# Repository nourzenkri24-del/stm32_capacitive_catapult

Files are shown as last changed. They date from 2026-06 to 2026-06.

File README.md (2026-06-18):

# stm32_capacitive_catapult

A catapult whose firing angle and power are controlled remotely by hand proximity, without any physical contact. The system uses a capacitive copper plate electrode to detect hand distance and translates it into real-time servo motor commands via an STM32 microcontroller.

> **Academic project** — Prototyping module, Mines Saint-Étienne (ISMIN), 2025–2026  

---

## How it works

A copper plate electrode forms a capacitor with the user's hand. As the hand moves closer, the total capacitance increases, which causes the frequency of a signal conditioner circuit to decrease (following F = 1 / (2 × R6 × Ctot)). The STM32 measures this frequency using a timer in **input capture mode**, applies a **10-point moving average filter** to smooth noise, then maps the filtered frequency to a servo angle via a linear law. Three servo motors control the catapult's firing angle, trajectory shape, and spoon locking mechanism.

```
Hand proximity → Capacitance variation → Signal conditioner (freq output) → STM32 input capture (TIM2)
→ Moving average filter → Frequency-to-angle mapping → PWM output (TIM1) → 3x Servo motors
```

---

## My contribution

- Full STM32 firmware (STM32CubeIDE, HAL): frequency measurement, filtering, state machine, PWM generation
- Timer configuration: TIM2 in input capture for frequency measurement, TIM1 for 3-channel PWM servo control
- 10-point moving average filter to stabilize noisy capacitive readings
- 6-state finite state machine controlling the full firing sequence
- KiCad system-level schematic (MCU + conditioner + servos + button)
- 3D mechanical design of the catapult structure
- Experimental calibration of sensor frequency range (29–62 kHz) and servo PWM limits (CCR 150–900)

> Signal conditioner circuit (schematic + PCB) provided by the school (Mines Saint-Étienne). I studied its operating principle and implemented the full STM32 integration and system logic.

---

## Hardware

| Component | Role |
|---|---|
| STM32 Nucleo L432KC | Microcontroller (32 MHz) |
| Copper plate electrode | Capacitive proximity sensor |
| Signal conditioner | Converts capacitance to variable-frequency square wave |
| Servo 1 (HS422) | Controls firing angle (trajectory shape) - range: 40°–125° |
| Servo 2 (HS422) | Controls horizontal orientation - range: 0°–180° |
| Servo 3 (HS422) | Locks / releases the spoon mechanism |
| Push button | Triggers state transitions |

**Sensor frequency range:** 29 kHz (hand close) → 62 kHz (hand far)  
**PWM period:** 20 ms (50 Hz) | CCR range: 150 (0°) → 900 (180°)

---

## State Machine

All transitions are triggered exclusively by button press, ensuring no accidental firing.

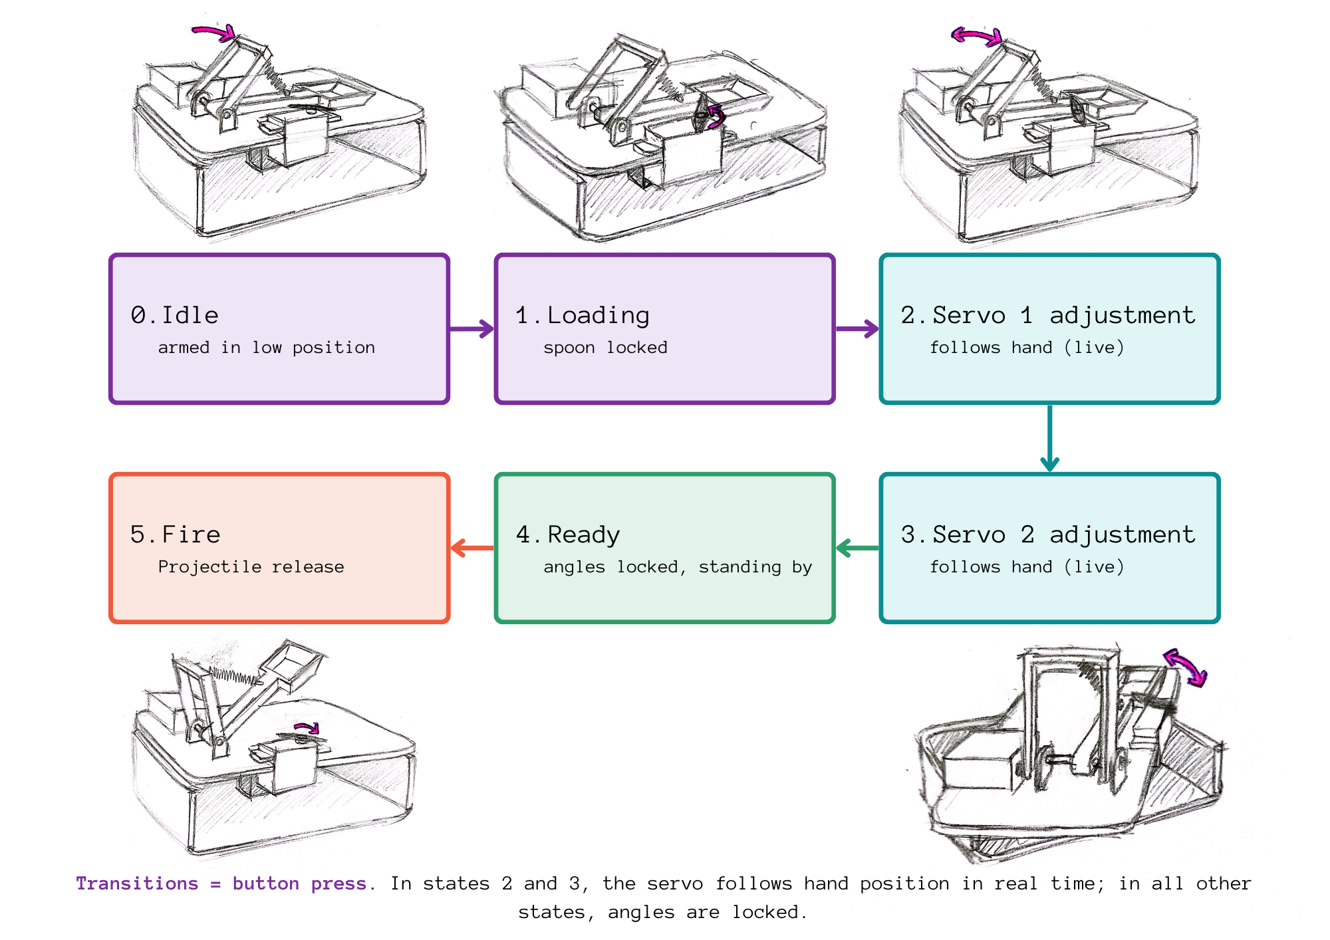
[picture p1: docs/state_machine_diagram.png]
State machine diagram


| State | Name | Description |
|---|---|---|
| 0 | Idle | Armed in high position, spoon released |
| 1 | Loading | Spoon locked by servo 3 |
| 2 | Servo 1 adjustment | Firing angle follows hand in real time |
| 3 | Servo 2 adjustment | Horizontal orientation follows hand in real time |
| 4 | Ready | All angles locked, waiting for fire command |
| 5 | Fire | Servo 3 releases spoon → projectile launched |

> In states 2 and 3, servo angles track hand position continuously. In all other states, angles are locked to their last set value.

---

## Firmware Architecture

```
main.c
├── HAL_TIM_IC_CaptureCallback()   ← ISR: measures period between rising edges (TIM2 CH1)
├── moving_average1()              ← 10-point sliding window filter
├── freq_to_angle()                ← Linear mapping [FREQ_MIN, FREQ_MAX] → [0°, 180°]
├── servo_angle_to_ccr()           ← Angle → PWM compare register value
└── main loop
    ├── Button polling + debounce (200 ms)
    ├── State machine transitions
    └── Per-servo angle selection based on current state → PWM update
```

Key implementation details:
- `diff1` (ISR-shared variable) is read with IRQ disabled to ensure atomic access
- Frequency is clamped to [FREQ_MIN, FREQ_MAX] before angle conversion to prevent out-of-range servo commands
- Servo 1 mechanical limits (40°–125°) enforced separately from servo 2 (0°–180°)

---

## System Schematic

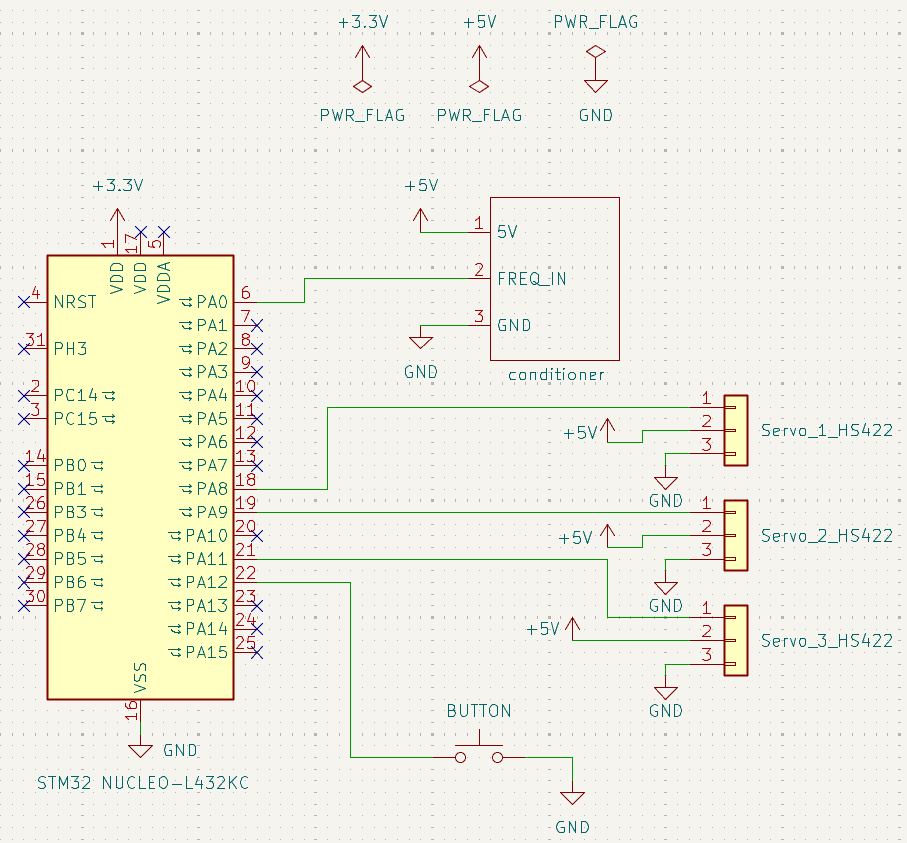
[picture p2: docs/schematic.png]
System schematic


---

## Demo

| | |
|---|---|
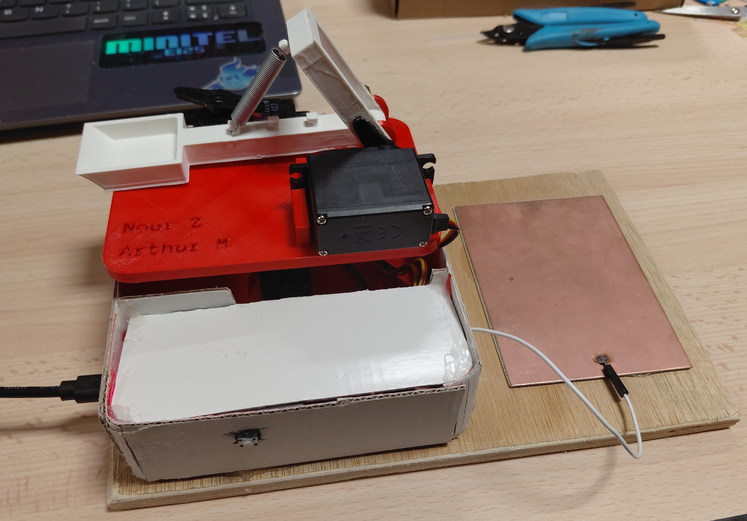
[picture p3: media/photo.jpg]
Catapult photo
|  | See [`media/`](media/) for demo video |

---

## Repository Structure

```
stm32-catapult/
├── Core/                        # STM32 firmware source (CubeIDE/HAL)
├── Drivers/                     # HAL + CMSIS libraries
├── schematics/                  # KiCad system schematic + PNG export
├── docs/
│   ├── state_machine_diagram.png
│   ├── schematic.png            # Schematic png
├── media/                       # Photos and demo video
├── cad/                         # 3D mechanical design files
├── stm32_catapult.ioc           # CubeMX configuration
├── STM32L432KCUX_FLASH.ld       # Linker script
└── README.md
```

---

## Known Limitations

- The frequency-to-distance relationship is hyperbolic (F ∝ 1/d), resulting in non-uniform angular resolution across the detection range
- The conditioner is sensitive to electromagnetic interference, introducing frequency fluctuations
- The capacitance formed between the electrode and the hand depends on hand surface, posture, and individual morphology — the system is not self-calibrating per user

## Possible Improvements

- Software compensation for the non-linearity of the transduction law
- Startup calibration procedure to normalize the frequency-angle mapping per user
- Guard electrode around the sensor plate to reduce EMI sensitivity

---

## Built With

- STM32CubeIDE (HAL, CubeMX)
- KiCad 10
- PartQuest Explore (circuit simulation)
- Fusion 360 / [your 3D tool] (mechanical design)

---

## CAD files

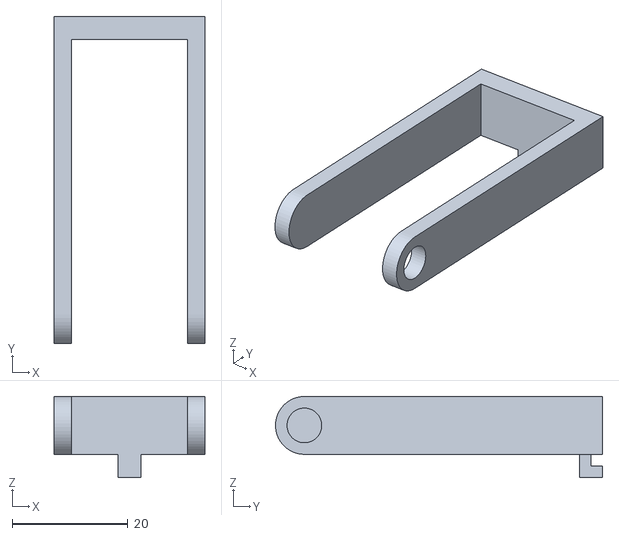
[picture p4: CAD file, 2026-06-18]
cad/spring_support.stl
26.0 x 56.5 x 14.0

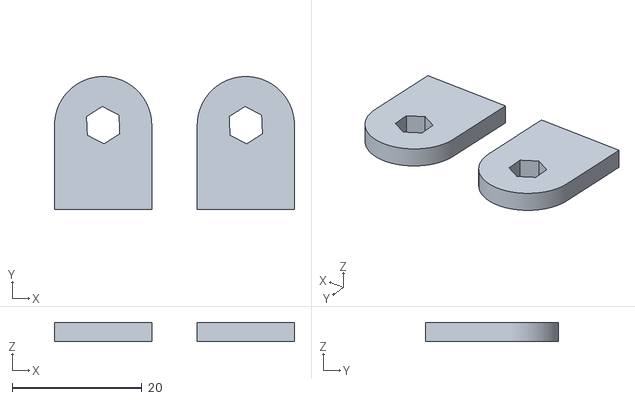
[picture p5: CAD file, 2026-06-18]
cad/part_embedded_in_the_base.stl
37.0 x 20.5 x 3.00

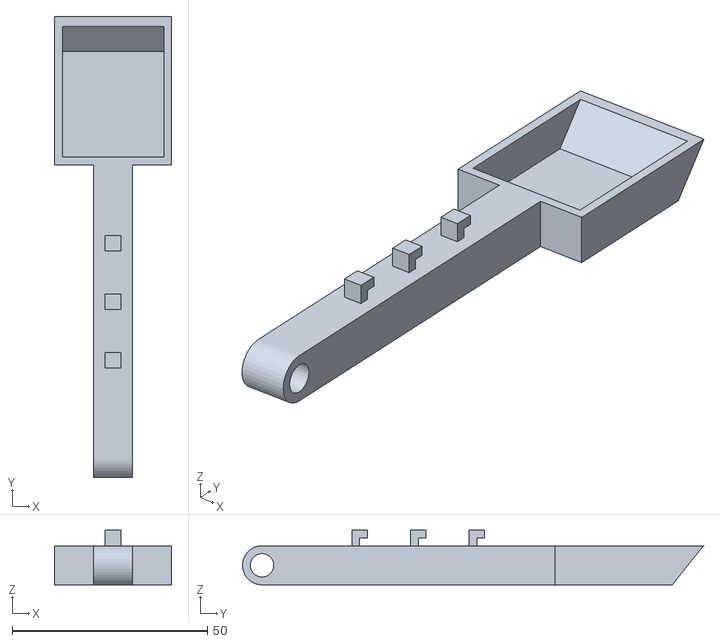
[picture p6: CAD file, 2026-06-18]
cad/Spoon.stl
30.0 x 118.0 x 14.0

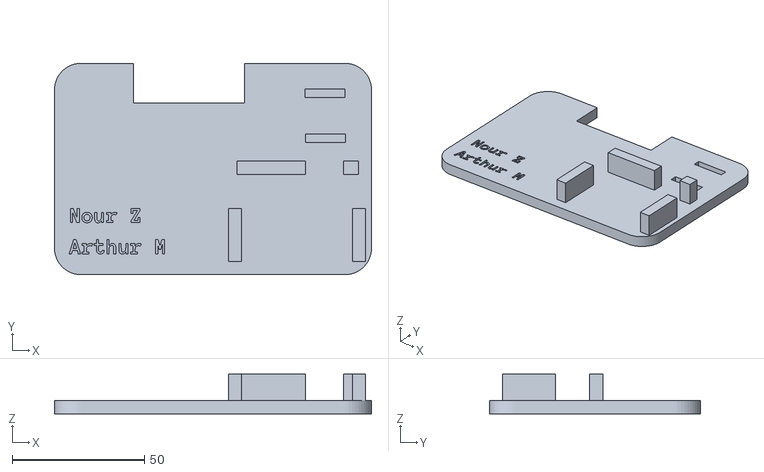
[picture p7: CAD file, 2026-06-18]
cad/base.stl
120.0 x 80.0 x 15.0

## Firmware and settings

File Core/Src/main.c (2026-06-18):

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
/* Includes ------------------------------------------------------------------*/
#include "main.h"

/* USER CODE BEGIN Includes */
#include <stdio.h>
#include <string.h>
/* USER CODE END Includes */

/* USER CODE BEGIN PTD */

// States of the state machine of the catapult
typedef enum {
    ETAT_REPOS      = 0,  // Initial position / Idle
    ETAT_RECHARGE   = 1,  // Recharge
    ETAT_SET_SERVO1 = 2,  // Interactive adjustment of servo 1
    ETAT_SET_SERVO2 = 3,  // Interactive adjustment of servo 2
	ETAT_ATTENTE    = 4,  // Wait
    ETAT_CATAPULTE  = 5,  // Fire
} Etat_t;

/* USER CODE END PTD */

/* USER CODE BEGIN PD */
#define TIMER_CLOCK_HZ   32000000.0f  // TIM2 clock frequency (Hz)
#define FREQ_MIN         29000.0f     // Minimal frequency of the entry (Hz)
#define FREQ_MAX         62000.0f     // Maximal frequency of the entry (Hz)
#define FILTER_SIZE      10           // Filter size
#define DEBOUNCE_MS      200          // Anti-rebound button (ms)

// Mechanical limits servo 1
#define SERVO1_ANGLE_MIN 40
#define SERVO1_ANGLE_MAX 125

// Mechanical limits servo 2 and 3
#define SERVO2_ANGLE_MIN 0
#define SERVO2_ANGLE_MAX 180
/* USER CODE END PD */

TIM_HandleTypeDef htim1;
TIM_HandleTypeDef htim2;

UART_HandleTypeDef huart2;

/* USER CODE BEGIN PV */

// ISR variables (volatile)
static volatile uint32_t ic1_prev       = 0;
static volatile uint32_t diff1          = 0;
static volatile uint8_t  first_capture1 = 0;
static volatile uint8_t  ready1         = 0;

// Filter
static uint32_t capture_buffer1[FILTER_SIZE] = {0};
static uint8_t  filter_index1  = 0;
static uint32_t filter_sum1    = 0;
static uint8_t  filter_count1  = 0;  // Number of valid samples (≤ FILTER_SIZE)

// State machine
static Etat_t   etat           = ETAT_REPOS;
static uint8_t  angle1_bloque  = 90;
static uint8_t  angle2_bloque  = 90;
static uint32_t last_button_time = 0;

// Mesured frequency
static uint32_t freq1 = 0;

// UART for debug
static char     uart_buf[64];
static uint16_t print_cnt = 0;

/* USER CODE END PV */

void SystemClock_Config(void);
static void MX_GPIO_Init(void);
static void MX_USART2_UART_Init(void);
static void MX_TIM2_Init(void);
static void MX_TIM1_Init(void);
/* USER CODE BEGIN PFP */
static uint32_t servo_angle_to_ccr(uint8_t angle, uint8_t angle_min, uint8_t angle_max);
static uint32_t moving_average1(uint32_t new_val);
static uint8_t  freq_to_angle(uint32_t freq);
/* USER CODE END PFP */

/* USER CODE BEGIN 0 */

// convert angle to ccr
static uint32_t servo_angle_to_ccr(uint8_t angle, uint8_t angle_min, uint8_t angle_max)
{
    if (angle < angle_min) angle = angle_min;
    if (angle > angle_max) angle = angle_max;
    return 150 + ((uint32_t)angle * 750) / 180;
}

// Moving average filter
// new_val is the new value to integrate.
static uint32_t moving_average1(uint32_t new_val)
{
    filter_sum1 -= capture_buffer1[filter_index1];
    capture_buffer1[filter_index1] = new_val;
    filter_sum1 += new_val;

    filter_index1 = (filter_index1 + 1) % FILTER_SIZE;

    if (filter_count1 < FILTER_SIZE)
    {
        filter_count1++;
    }

    // Avoid division by zero on the first call
    if (filter_count1 == 0)
    {
        return new_val;
    }

    return filter_sum1 / filter_count1;
}

// Converts a sensor frequency into a servo angle (0°–180°).
/* The frequency is clamped to [FREQ_MIN, FREQ_MAX] before conversion
 to prevent overflow or out-of-range values. */
static uint8_t freq_to_angle(uint32_t freq)
{
    float f = (float)freq;
    if (f < FREQ_MIN) f = FREQ_MIN;
    if (f > FREQ_MAX) f = FREQ_MAX;
    return (uint8_t)(180.0f - (FREQ_MAX - f) * 180.0f / (FREQ_MAX - FREQ_MIN));
}

/* USER CODE END 0 */

/**
  * @brief  The application entry point.
  * @retval int
  */
int main(void)
{

  /* MCU Configuration--------------------------------------------------------*/

  /* Reset of all peripherals, Initializes the Flash interface and the Systick. */
  HAL_Init();

  /* Configure the system clock */
  SystemClock_Config();

  /* Initialize all configured peripherals */
  MX_GPIO_Init();
  MX_USART2_UART_Init();
  MX_TIM2_Init();
  MX_TIM1_Init();
  /* USER CODE BEGIN 2 */
    HAL_TIM_PWM_Start(&htim1, TIM_CHANNEL_1);
    HAL_TIM_PWM_Start(&htim1, TIM_CHANNEL_2);
    HAL_TIM_PWM_Start(&htim1, TIM_CHANNEL_4);

    HAL_TIM_IC_Start_IT(&htim2, TIM_CHANNEL_1);
    // UART TEST at startup
    char test_buf[32];
    uint8_t test_len = sprintf(test_buf, "boot ok\r\n");
    HAL_UART_Transmit(&huart2, (uint8_t *)test_buf, test_len, 1000);
  /* USER CODE END 2 */

  /* Infinite loop */
  /* USER CODE BEGIN WHILE */

		if (HAL_GPIO_ReadPin(GPIOA, GPIO_PIN_12) == GPIO_PIN_RESET)
		{
			uint32_t now = HAL_GetTick();
			if ((now - last_button_time) > DEBOUNCE_MS)
			{
				last_button_time = now;
				switch (etat)
				{
					case ETAT_REPOS:
						etat = ETAT_RECHARGE;
						break;
					case ETAT_RECHARGE:
						etat = ETAT_SET_SERVO1;
						break;
					case ETAT_SET_SERVO1:
						angle1_bloque = freq_to_angle(freq1);
						etat = ETAT_SET_SERVO2;
						break;
					case ETAT_SET_SERVO2:
						angle2_bloque = freq_to_angle(freq1);
						etat = ETAT_ATTENTE;
						break;
					case ETAT_ATTENTE:
						etat = ETAT_CATAPULTE;
						break;
					case ETAT_CATAPULTE:
						etat = ETAT_REPOS;
						break;
					default:
						etat = ETAT_REPOS;
						break;
				}
			}
		}

		if (ready1)
		{
			uint32_t local_diff;
			__disable_irq();
			local_diff = diff1;
			ready1 = 0;
			__enable_irq();

			uint32_t diff_filtered = moving_average1(local_diff);
			freq1 = (diff_filtered > 0) ? (uint32_t)(TIMER_CLOCK_HZ / (float)diff_filtered) : 0;

			uint8_t angle_live = freq_to_angle(freq1);

			uint8_t angle1;
			if (etat == ETAT_REPOS || etat == ETAT_RECHARGE)
				angle1 = SERVO1_ANGLE_MAX;
			else if (etat == ETAT_SET_SERVO1)
				angle1 = angle_live;
			else
				angle1 = angle1_bloque;

			__HAL_TIM_SET_COMPARE(&htim1, TIM_CHANNEL_1,
				servo_angle_to_ccr(angle1, SERVO1_ANGLE_MIN, SERVO1_ANGLE_MAX));

			uint8_t angle2 = (etat == ETAT_SET_SERVO2) ? angle_live : angle2_bloque;
			__HAL_TIM_SET_COMPARE(&htim1, TIM_CHANNEL_2,
				servo_angle_to_ccr(angle2, SERVO2_ANGLE_MIN, SERVO2_ANGLE_MAX));

			uint8_t angle3 = (etat == ETAT_REPOS || etat == ETAT_CATAPULTE) ? 180 : 90;
			__HAL_TIM_SET_COMPARE(&htim1, TIM_CHANNEL_4,
				servo_angle_to_ccr(angle3, SERVO2_ANGLE_MIN, SERVO2_ANGLE_MAX));

			if (++print_cnt >= 500)
			{
				print_cnt = 0;
				if (huart2.gState == HAL_UART_STATE_READY)
				{
					uint8_t len = sprintf(uart_buf, "freq=%lu Hz  angle=%u\r\n",
										  freq1, (unsigned)freq_to_angle(freq1));
					HAL_UART_Transmit_IT(&huart2, (uint8_t *)uart_buf, len);
				}
			}
		}

    /* USER CODE END WHILE */

    /* USER CODE BEGIN 3 */
  }
  /* USER CODE END 3 */

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
/* USER CODE BEGIN 4 */

// TIM input capture callback.
// Measures the period between two rising edges on TIM2 CH1.
// diff1 contains the number of ticks between two successive captures.
// ready1 is set to 1 to signal that a new measurement is available.

void HAL_TIM_IC_CaptureCallback(TIM_HandleTypeDef *htim)
{
    if (htim->Instance == TIM2 && htim->Channel == HAL_TIM_ACTIVE_CHANNEL_1)
    {
        uint32_t capture = HAL_TIM_ReadCapturedValue(htim, TIM_CHANNEL_1);

        if (!first_capture1)
        {
            ic1_prev       = capture;
            first_capture1 = 1;
        }
        else
        {
            diff1  = capture - ic1_prev;
            ic1_prev = capture;
            ready1 = 1;
        }
    }
}

/* USER CODE END 4 */
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


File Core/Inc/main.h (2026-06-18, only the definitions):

#define VCP_TX_Pin GPIO_PIN_2
#define VCP_TX_GPIO_Port GPIOA
#define BUTTON1_Pin GPIO_PIN_12
#define BUTTON1_GPIO_Port GPIOA
#define SWDIO_Pin GPIO_PIN_13
#define SWDIO_GPIO_Port GPIOA
#define SWCLK_Pin GPIO_PIN_14
#define SWCLK_GPIO_Port GPIOA
#define VCP_RX_Pin GPIO_PIN_15
#define VCP_RX_GPIO_Port GPIOA
#define LD3_Pin GPIO_PIN_3
#define LD3_GPIO_Port GPIOB

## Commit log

2026-06-18 First part project upload
    [Spoon.stl, base.stl, catapulte.kicad_sch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]
2026-06-18 Update schematic image path in README
2026-06-18 Update schematic image reference in README

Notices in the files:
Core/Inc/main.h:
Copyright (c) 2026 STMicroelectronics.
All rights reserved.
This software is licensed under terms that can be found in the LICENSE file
